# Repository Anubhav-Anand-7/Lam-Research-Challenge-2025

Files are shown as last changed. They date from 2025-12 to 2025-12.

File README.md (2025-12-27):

# Circuit Raja – Hardware Hustle: Lam Research Challenge 2025

## Overview
This repository contains the complete system design and technical implementation for the **Hardware Hustle Round : Lam Research Challenge 2025**, developed by **Team Circuit Raja (Team ID: LRC-U-0053-6)**.

The solution consists of two coordinated robots and a centralized arena automation system designed to operate reliably under real-time constraints and complete all tasks within the competition time limit.

---

## System Architecture
The system follows a **Decentralized & Deterministic Control Philosophy** to eliminate latency bottlenecks and ensure predictable behavior.

### Major Subsystems
- **Advanced Line Follower Robot (ALFR)** – Autonomous navigation and safety
- **Single Arm Robot (SARM)** – Manual operation with automated manipulation
- **Arena Automation System** – Event-driven gate control
- **Custom Peristaltic Pump** – Precision fluid dispensing

---

## Advanced Line Follower Robot (ALFR)
- 8-channel analog line sensor array with **PD control**
- **Interrupt-driven ultrasonic obstacle detection** for instant emergency stops
- High-speed, stable navigation through sharp curves and S-paths
- Line re-acquisition using last-known turn memory
- Constrained motor control for safe and consistent behavior

---

## Single Arm Robot (SARM)
- **Dual-ESP32 decentralized architecture**
  - **Base Controller:** Mecanum wheel mobility and kinematics
  - **Arm Controller:** 5-DOF robotic arm and gripper control
- Omni-directional movement for precise obstacle handling
- Predefined arm **state macros** for fast, repeatable manipulation
- **Dual-pilot operation** using two independent Bluetooth Android apps
- Modified gripper with high-friction compliant padding for reliable pickup

---

## Arena Circuitry & Automation
- Centralized MCU with **non-blocking firmware design**
- **Gate 1:** Relay-controlled peristaltic pump dispensing exactly **125 mL**
- **Gate 2:** 5-second LED activation using `millis()` (non-blocking)
- **Gate 3:** Load cell (HX711) based weight verification
- TFT display showing team identity and real-time weight data

---

## Peristaltic Pump
- Custom 3D-printed positive displacement pump
- Three-roller design for continuous, backflow-free operation
- Flow rate derived analytically and calibrated experimentally
- Software-adjustable timing to maintain ±5% volume accuracy

---

## Key Design Highlights
- Deterministic PD control over heuristic methods
- Hardware interrupts for safety-critical sensing
- Parallel execution using multi-core and multi-operator strategies
- Fully non-blocking arena automation logic

---

## Team
**Circuit Raja**  
Hardware Hustle – Lam Research Challenge 2025  
Submission Date: **November 2025**

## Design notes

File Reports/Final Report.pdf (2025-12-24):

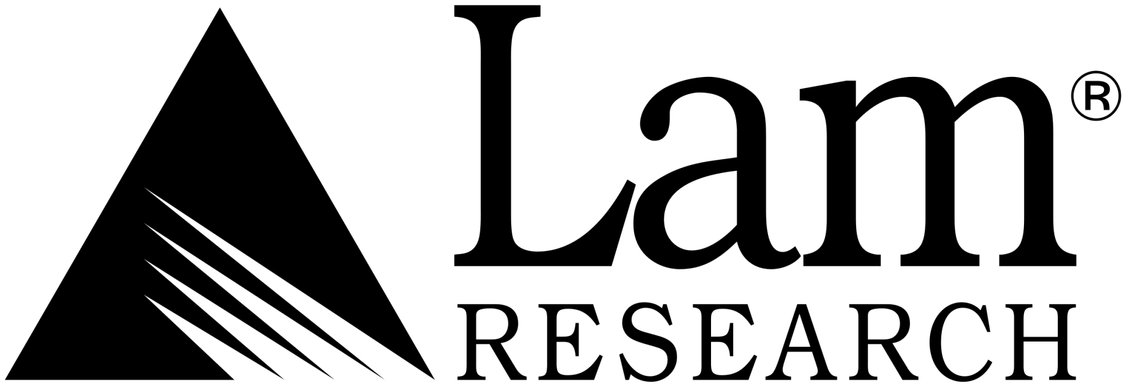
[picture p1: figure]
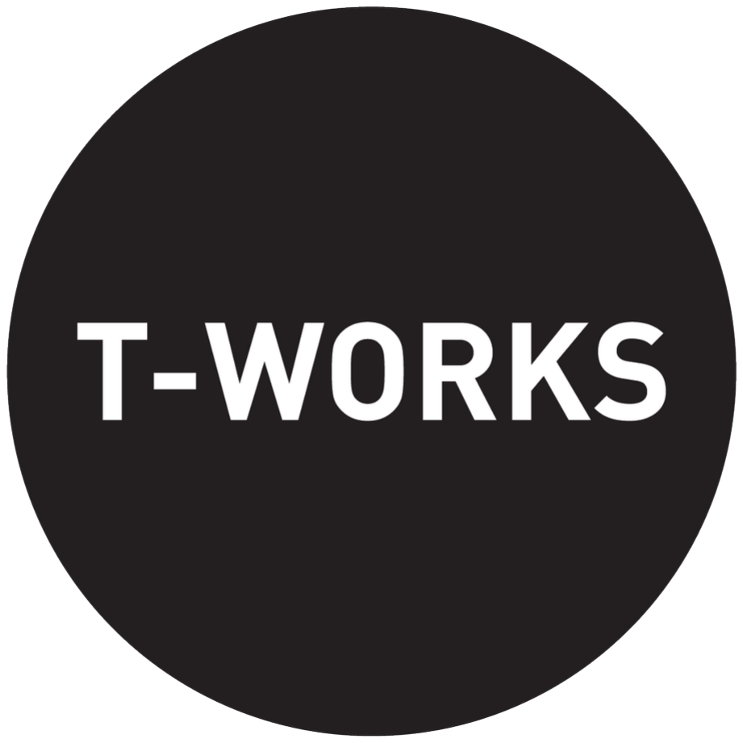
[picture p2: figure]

# Hardware Hustle: Lam Research Challenge 2025

### Design Technical Documentation

Submitted By:

# Circuit Raja

Team ID: LRC-U-0053-6

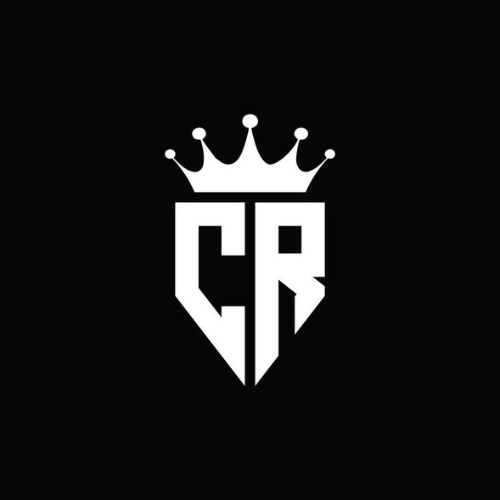
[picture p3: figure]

November 2025

Circuit Raja | Hardware Hustle: Lam Research Challenge 2025

### Contents

1 System Overview | 2
2 Advanced Line Follower Robot (ALFR) | 3
3 Single Arm Robot (SARM) Design | 5
4 Arena Circuitry & Automation Design | 7
5 Peristaltic Pump Development | 9
Confidential Design Document | Page 1

### 1 System Overview

### 1.1 Problem Statement Overview

The Hardware Hustle challenge requires two coordinated robots—a manually controlled Single Arm Robot (SARM) and an autonomous Advanced Line Follower Robot (ALFR)—to complete a sequence of tasks inside a predefined arena. ALFR must follow the line path, halt at obstacles, trigger Gate 1 for fluid dispensing, Gate 2 for LED activation, and park at Gate 3 for load-cell weight verification. SARM’s role is to remove obstacles blocking ALFR’s route. The entire system must operate accurately and finish within the 10-minute time limit.

### 1.2 Design Philosophy: Decentralized & Deterministic

Our team adopted a philosophy of “Decentralized Architecture & Deterministic Control.” Analyzing the complexity of the Hardware Hustle challenge, we determined that a single microcontroller loop would introduce unacceptable latency when handling simultaneous tasks—such as inverse kinematics, sensor interrupts, and wireless communication. Therefore, we engineered a system where critical subsystems operate on independent processing cores. This ensures that heavy computational tasks never block safety-critical functions like obstacle detection. We prioritized predictability over raw speed, using mathematical models (PID) and hardware interrupts to guarantee the robot behaves exactly the same way in every run.

### 1.3 Technical Implementation Strategies

1. SARM: Dual-Core Decentralization
To ensure zero latency during the manual operation phase, the Single Arm Robot (SARM) utilizes a split-architecture approach, as detailed in our firmware source files:
- Base Controller (Mobility): A dedicated ESP32 handles the Mecanum wheel kinematics. The code processes directional vectors (Forward, Backward, Strafe Left/Right) and maps them to the L298N drivers independently of the arm’s status.
- Arm Controller (Manipulation): A second ESP32 manages the 5-DOF servo arm. We
implemented “State Macros” such as moveArmContracted() and moveArmExpanded().
These macros allow the operator to trigger complex folding sequences with a single button press, ensuring the gripper geometry is always perfectly aligned for obstacle pickup.
2. ALFR: Interrupt-Driven Safety Layer
For the Autonomous Line Follower, we moved away from standard polling loops to achieve deterministic safety:
- Hardware Interrupts: We utilized a hardware Interrupt Service Routine (ISR) for the ultrasonic sensor (echoISR). This allows the emergencyStop flag to trigger in microseconds, instantly overriding the motor drivers the moment an object is detected, regardless of the main loop’s cycle time.
- PID Stabilization: We implemented a Proportional-Derivative control loop to handle the arena’s S-curves.
PIDvalue = (Kp × Error) + (Kd × (Error − PreviousError)) | (1)

With tuned constants (Kp = 40, Kd = 6), the robot adjusts motor differential speed dynamically based on the weighted average of the 8-channel sensor array.

3. Arena: Non-Blocking Automation
The Arena Controller serves as the central logic node. To satisfy the Gate 2 requirement without freezing the system, we utilized a millis() based non-blocking timer rather than delay(). This ensures the controller can still read the Gate 3 Load Cell sensors even while the Gate 2 LEDs are active.

### 2 Advanced Line Follower Robot (ALFR)

### 2.1 Mechanical Integration

The ALFR chassis is a custom 3D-printed assembly designed for low center-of-mass stability.

- Sensor Placement: The 8-channel analog line sensor array is mounted at the extreme anterior of the chassis. This forward offset provides a crucial “look-ahead” buffer, allowing the PID algorithm to react to the arena’s sharp radii (R140mm and R150mm) before the drive wheels reach the curve.
- Obstacle Detection: An HC-SR04 ultrasonic sensor is mounted centrally at a height of 40mm, optimized to detect the standard obstacle blocks used in Stages 1, 2, and 3.

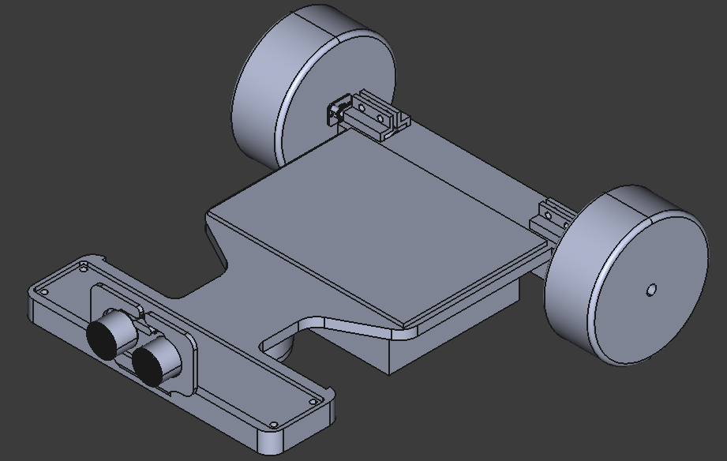
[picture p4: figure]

Figure 1: ALFR CAD

### 2.2 Control Algorithms

Unlike basic threshold-based followers, our ALFR utilizes a deterministic PD (Proportional-Derivative) control loop to ensure smooth trajectory maintenance.

### 1. PD Implementation

The core navigation logic calculates the positional error relative to the center of the sensor array. This error is processed through the following control equation:

Correction = (Kp · Error) + (Kd

- (Error − Errorprev)) | (2)

Based on our testing, we tuned the gain constants to:

- Proportional Gain (Kp = 40.0): Provides immediate reaction to track deviation.
- Derivative Gain (Kd = 6.0): Dampens oscillations, preventing the robot from “fishtailing” on straight sections.

This mathematical approach allows the ALFR to vary the motor differential speed dynamically (‘dynBase‘), maintaining a high base speed while slowing down only as much as necessary for turns.

### 2. Interrupt-Driven Obstacle Avoidance

To strictly adhere to the rule that the ALFR must “Wait if Obstacle Present” (Rulebook Page 4), we implemented a hardware-interrupt safety layer.
Instead of polling the sensor in the main loop (which can be delayed by PID calculations), we attached an Interrupt Service Routine (ISR) to the Ultrasonic Echo pin:

void echoISR() {
// Calculates distance immediately upon signal return
if (distance < 20) emergencyStop = true;
}

This architecture ensures that if an obstacle is placed within 20cm, the robot halts in microseconds, independent of the main processor load.

### 2.3 Code Uniqueness

- Memory Buffer: The system utilizes a lastTurn variable. If the robot completely loses the line (e.g., at a sharp acute angle), it recalls the direction of the last known error and performs a rotational search in that direction until the line is re-acquired.
- Hardware-Level Pin State Check: Rising/falling edges of the echo signal are detected by checking

if (PIND & (1 << PIND3))
This is faster and more precise than using digitalRead(), giving microsecond accuracy to
the distance measurement.
- Constrained Motor Control for Safe Behavior: Motor outputs are bounded using constrain() to ensure safe acceleration and consistent turning behavior. This prevents electrical and mechanical stress on the motors during sharp PID corrections.

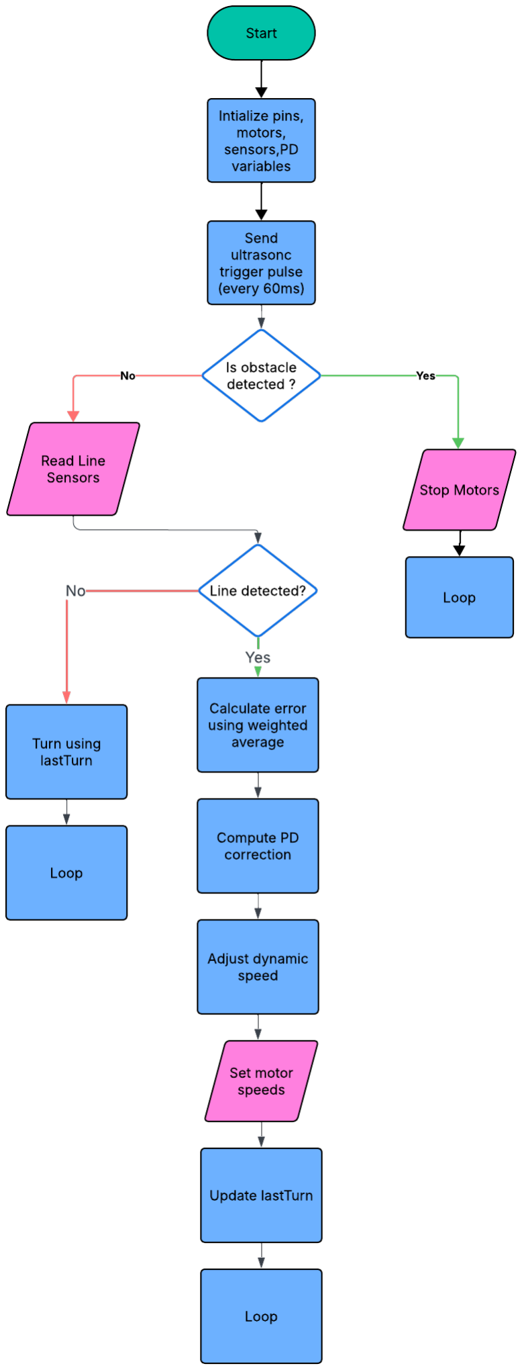
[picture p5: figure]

Figure 2: ALFR Algorithm flowchart

### 3 Single Arm Robot (SARM) Design

### 3.1 Control Architecture: Dual-Core Decentralization

To mitigate latency and ensure real-time responsiveness during the manual operation phase, we developed a Decentralized Control System. Unlike traditional single-board designs, our SARM separates mobility and manipulation into independent processing nodes:

- Node A (Mobility Controller): An ESP32 running SARM base code.ino is dedicated exclusively to the Mecanum wheel inverse kinematics. It parses directional vectors (Forward, Strafe, Rotate) via Bluetooth without servo signal interference.
- Node B (Arm Controller): A secondary ESP32 running Final SARM arm code.ino manages the 5-DOF robotic arm. This separation ensures that the PWM signals for the servos remain stable even when the motors are drawing high current during rapid acceleration.

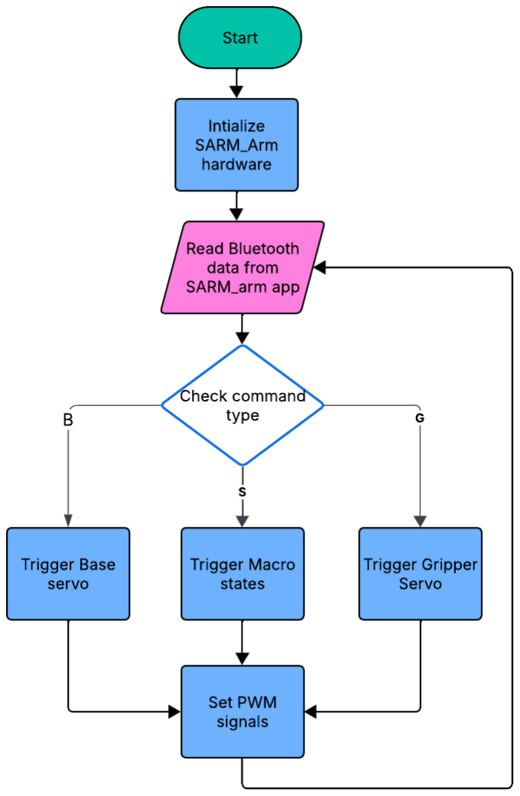
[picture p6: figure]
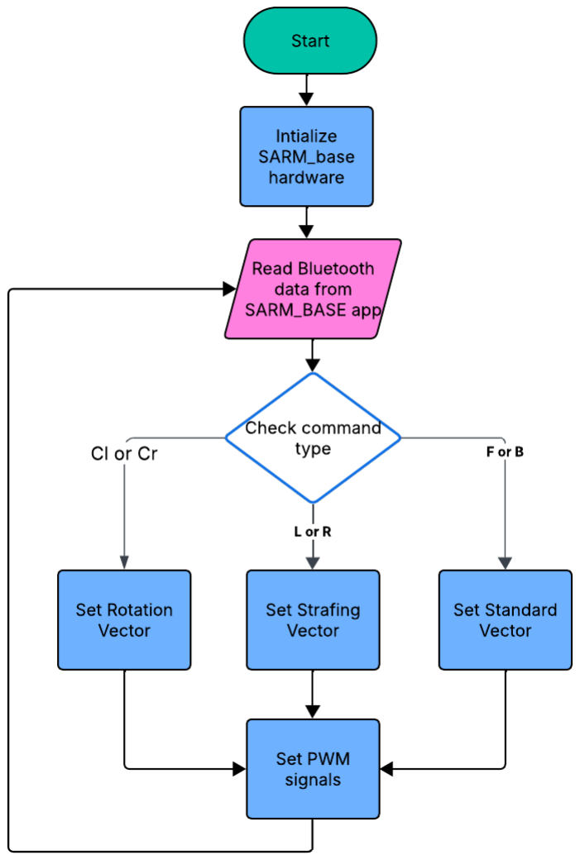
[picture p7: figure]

Figure 3: Node A Algorithm flowchart | Figure 4: Node B Algorithm flowchart

### 3.2 Omni-Directional Mobility

The base utilizes four independently driven Mecanum wheels. The drive logic leverages vector cancellation to achieve holonomic movement. As implemented in our firmware function void
left():

// Vector Math for Left Strafe
Motor1 (Front-Left): Backward Motor2 (Front-Right): Forward

Motor3 (Rear-Right): | Forward
Motor4 (Rear-Left): | Backward

This configuration allows the operator to align with obstacles laterally without needing to perform complex multi-point turns, significantly reducing cycle time.

### 3.3 Automated Manipulation Logic

To minimize operator fatigue and error, we moved away from raw manual control for every joint. Instead, we implemented State Macros pre-calculated geometric configurations hardcoded into the firmware.

- Contracted State (Safety): Defined in code as contracted shoulder = 140, this macro folds the arm entirely within the chassis footprint. This allows the robot to travel at maximum speed without the arm changing the center of gravity or colliding with arena walls.
- Expanded/Grip State: Defined as expanded elbow = 30, this macro automatically positions the end-effector at the exact height of the obstacle blocks (Z ≈ 40mm), removing the need for the operator to manually estimate depth.

### 3.4 Dual-Pilot Operational Strategy

Innovation: Two Apps, Two Pilots, Zero Lag
To overcome the inherent latency limitations of standard Bluetooth stacks and reduce the cognitive load on a single operator, we engineered a Split-Control HMI (Human-Machine Interface).
Instead of a single app, we developed two distinct custom Android applications:
1. Pilot App (Navigation): Pairs exclusively with the Base ESP32 (“SARM BASE”). This allows the primary pilot to focus solely on high-speed maneuvering and obstacle approach vectors.
2. Co-Pilot App (Manipulation): Pairs exclusively with the Arm ESP32 (“ESP32 ARM”). This allows the secondary pilot to trigger the gripper macros (Open/Close, Fold/Extend) independently.

Strategic Advantage: This ‘Rally Car’ style coordination (Driver + Navigator) allows the arm to begin unfolding while the base is still moving toward the target. This parallel execution effectively doubles our operational bandwidth and significantly reduces the total cycle time per obstacle compared to a single-pilot workflow.

### 3.5 Gripper Design & Modification

The standard gripper design provided in the reference kit was analyzed and found to lack sufficient friction for the arena obstacles. To address this, we engineered the following modifications:

1. Adaptive Contact Geometry: Unlike a rigid geometric modification, we retained the standard gripper structure but integrated a compliant interface. The compressible nature of the foam pads allows the jaw profile to dynamically deform and mold itself to the obstacle’s shape, effectively increasing the contact surface area upon closure.

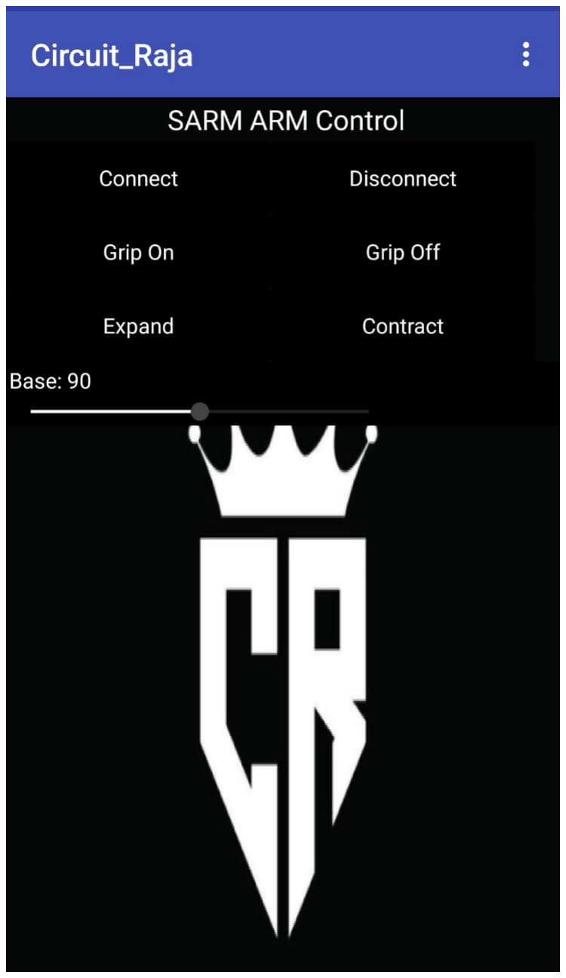
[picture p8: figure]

Figure 5: SARM
Arm GUI

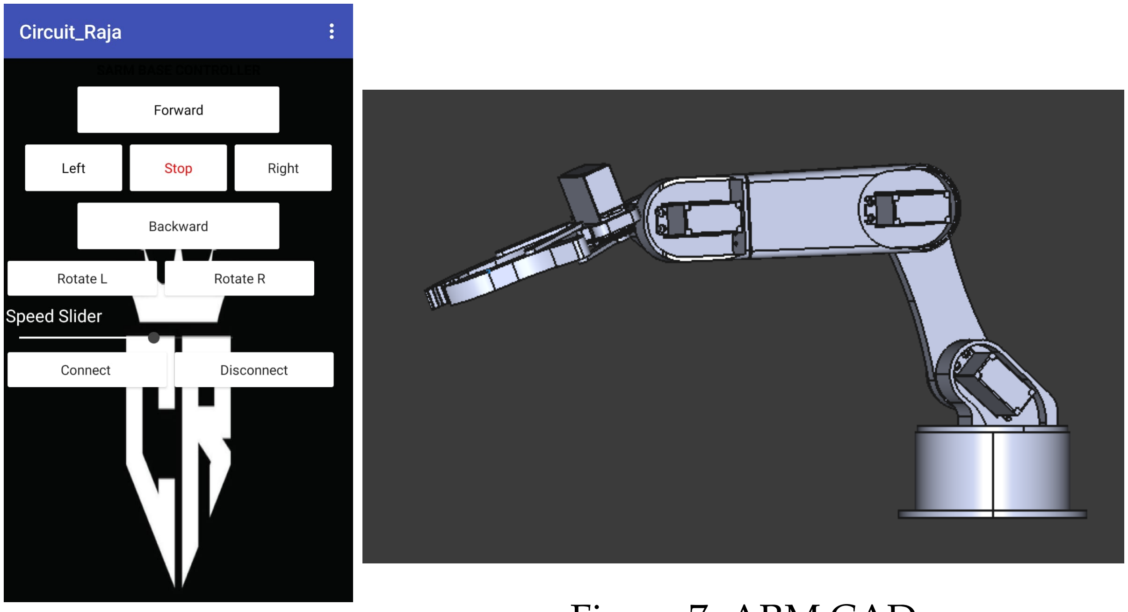
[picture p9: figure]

Figure 6: SARM
Base GUI

Figure 7: ARM CAD

2. Surface Material Enhancement: We applied high-density adhesive foam padding to the inner jaw faces. This modification significantly increases the coefficient of friction compared to bare PLA and provides mechanical damping, ensuring the obstacle does not slip or vibrate loose during high-speed acceleration.
3. Kinematic Redesign (5-Bar to 4-Bar Conversion): The original gripper design utilized a 5-bar linkage mechanism, which is under-actuated when driven by a single motor. To resolve this instability, we rigidly fixed two of the intermediate links at the pivot joint.

### 4 Arena Circuitry & Automation Design

### 4.1 Centralized Arena Control Architecture

To ensure synchronized game states across all three stages, we implemented a Centralized Event-Driven Architecture. A single Microcontroller Unit (MCU) monitors the state of all three gates simultaneously.
Unlike basic sequential systems, our firmware utilizes Non-Blocking I/O logic. This allows the system to manage the Gate 2 LED timers while simultaneously polling the Gate 3 Load Cell data, preventing any blind spots in the sensing loop.

### 4.2 Gate 1: Precision Fluid Delivery System

Objective: Dispense exactly 125ml of fluid upon ALFR detection.

- Hardware Integration: We utilized a 5V Relay Module (controlled via Pin 14) to switch the high-current DC Peristaltic Pump. The trigger is a digital IR sensor (Pin 16) configured as INPUT PULLUP (Active LOW).
- Flow Control Logic: Instead of relying on variable voltage, we operate the pump at a fixed 12V to ensure a constant flow rate (Q). The dispense volume is controlled purely by time (t):

tdispense =

Vtarget

Qpump

(3)

The code waits for the sensorState == LOW signal to close the relay circuit.

### 4.3 Gate 2: Timer-Based LED Activation

Objective: Illuminate the Lam LED array for 5 seconds without blocking system processes. Innovation - Non-Blocking Timer: Standard delay(5000) functions would freeze the processor, preventing it from detecting the robot at Gate 3 if it moved quickly. To solve this, we implemented a millis() based timer in the code:

if (sensorState2 == LOW) {
relay2Active = true; | // Set Flag
relay2TimerStart = millis(); // Start Stopwatch
}
// Check time difference in every loop cycle
if (relay2Active && (millis() - relay2TimerStart >= 5000)) {
turnOffLEDs(); | // Auto-Reset
}

This ensures the visual effects (Gate 2) do not interfere with the critical data collection (Gate 3).

### 4.4 Gate 3: Validation Node (Load Cell & LCD)

Objective: Verify fluid weight and display Team Identity.

1. Weight Sensing (HX711): We interfaced a 5kg Load Cell via an HX711 24-bit ADC (Pins 32/33). To ensure accuracy despite vibration, the code takes a 10-sample moving average (scale.get units(10)) before validating the success condition.
2. Visual Feedback (ST7735): Upon successful weight verification, the system drives an ST7735 TFT Display via SPI. As a unique team identifier, the display renders:
- Team Handle: ”Circuit RAJA”
- Custom Bitmap: smile bmp (Visual success indicator)
- Real-time Weight Value

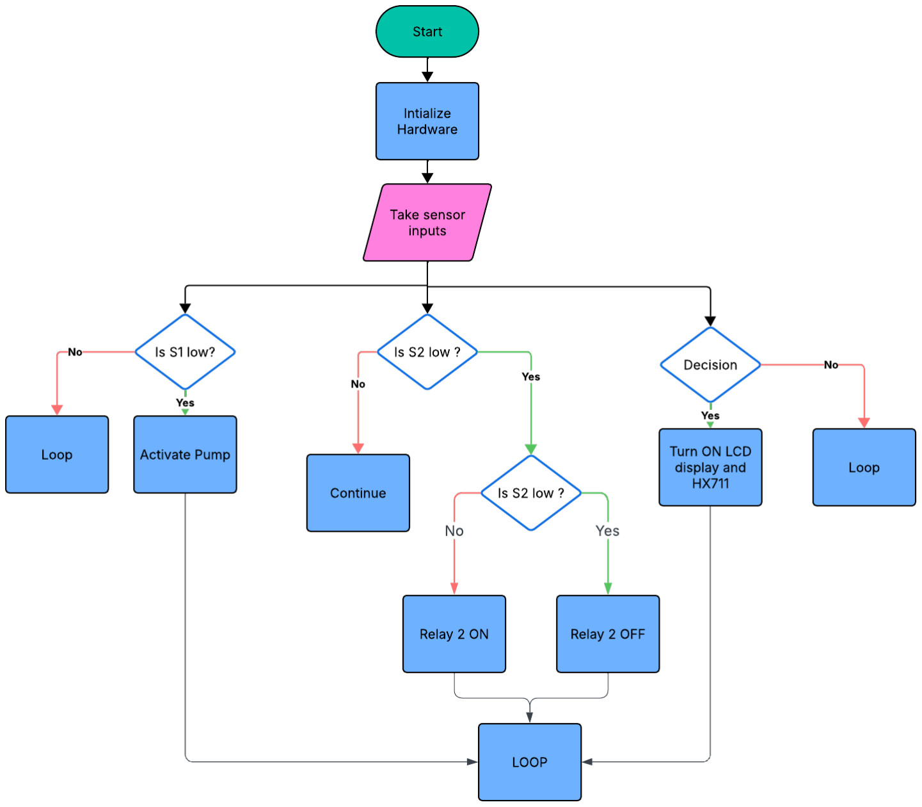
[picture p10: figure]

Figure 8: Arena Algorithm flowchart

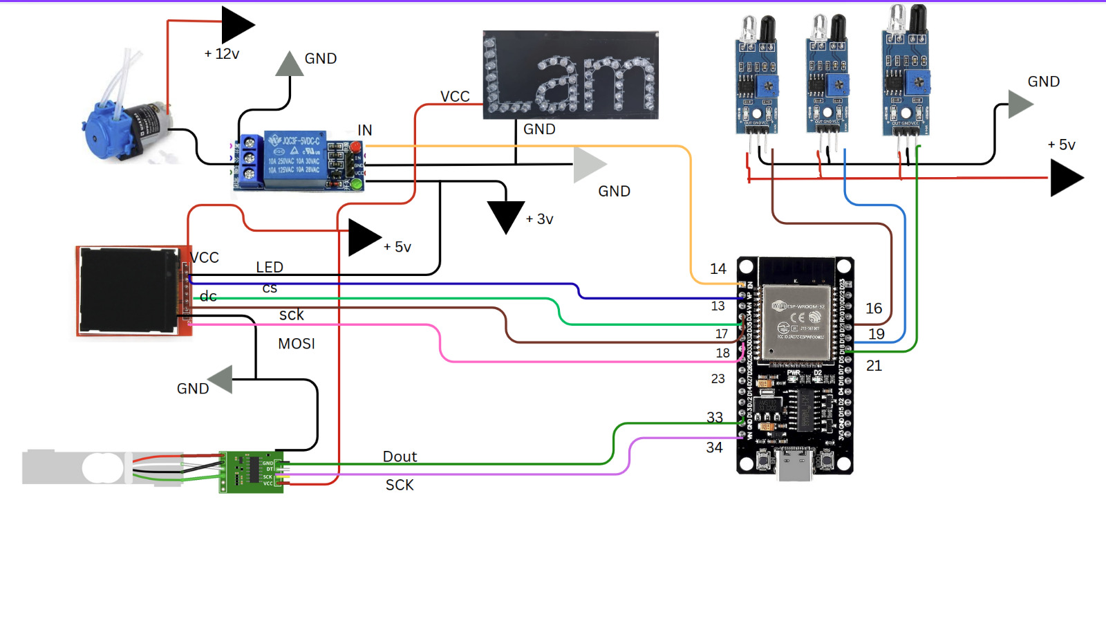
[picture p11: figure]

Figure 9: Arena Circuit Schematic

### 5 Peristaltic Pump Development

### 5.1 Mechanical Design Principle

To achieve the specific fluid delivery requirement of 125 mL at Gate 1, we engineered a custom positive displacement pump. The mechanism relies on a rotating three-roller configuration that progressively compresses a flexible silicone tube against a circular stator.

- Stator Geometry: Designed with a track radius (R) of 25 mm to support the tubing without over-compression.
- Rotor Configuration: A three-roller design was selected to ensure continuous flow and prevent backflow (siphoning) when the motor stops[cite: 273].
- Coupling: A custom-designed 3D-printed mount aligns the 600 RPM DC motor shaft directly with the rotor assembly[cite: 274, 288].

### 5.2 Flow Rate Mathematics

To strictly control the dispensed volume, we derived the theoretical flow rate based on the tubing geometry (2 mm Internal Diameter).

1. Volume per Revolution (Vrev): Using the tube cross-sectional area (A) and the path circumference (C):
Vrev = A × C ≈ 0.492mL/rev | (4)
Derived from A = 3.14 × 10⁻⁶m² and C = 0.157m[cite: 280, 283, 286].
2. Time Calculation (t): With a motor speed of 600 RPM (10rev/s) and an estimated mechanical efficiency of 90%, the actual flow rate is calculated as:
Qactual ≈ 4.43mL/s | (5)

Therefore, the required activation time to dispense 125 mL is:

t =

125mL
4.43mL/s
≈ 28seconds | (6)

This duration falls well within the competition limits.

### 5.3 Manufacturing & Calibration

The pump components (Housing and Rotor) were manufactured using FDM 3D printing with PLA/PETG filaments for structural rigidity.
Calibration Strategy: Although the theoretical calculation yields ∼ 28 seconds, we implemented a software calibration routine in the Arena Controller:
1. Run pump for fixed interval (10s).
2. Measure dispensed mass.
3. Adjust the relay1 active duration in the code based on the experimental flow rate to ensure ±5% accuracy.

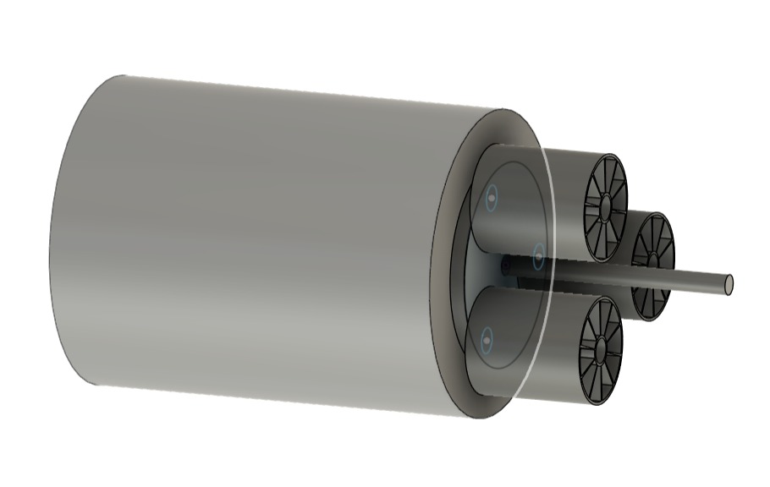
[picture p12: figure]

Figure 10: Side view of the pump

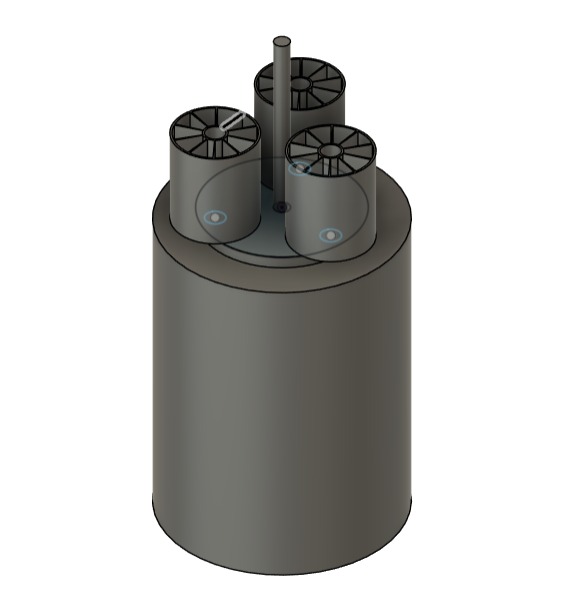
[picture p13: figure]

Figure 11: Isometric view of the pump

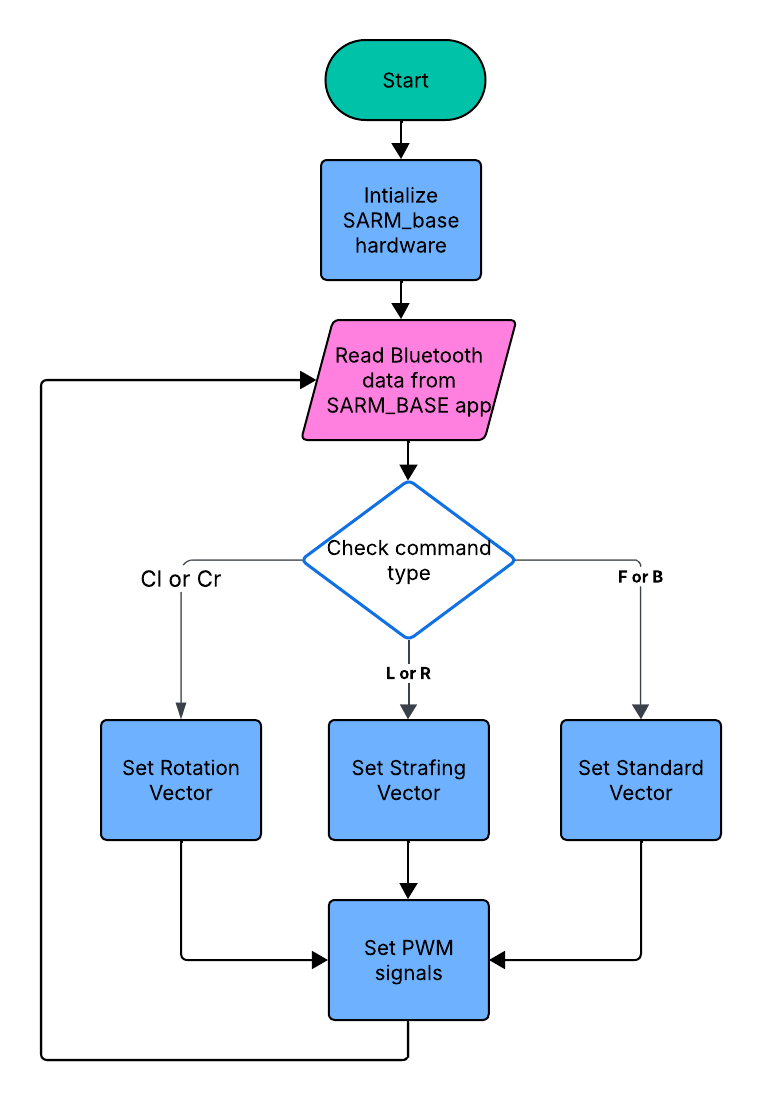
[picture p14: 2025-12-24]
Firmware & Flowchart/SARM/SARM_Base_flowchart.png

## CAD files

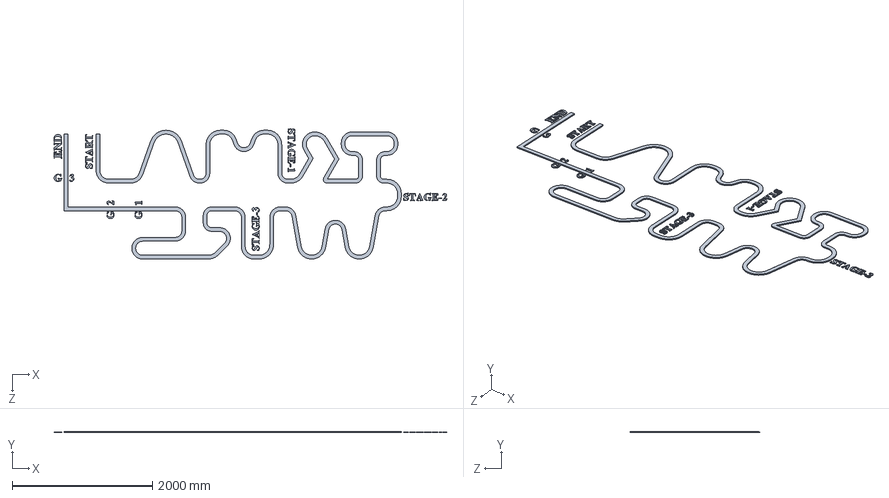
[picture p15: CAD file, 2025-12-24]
3D Files/Arena/FINAL_ARENA.SLDPRT
5611.0 x 15.0 x 1858.3 mm

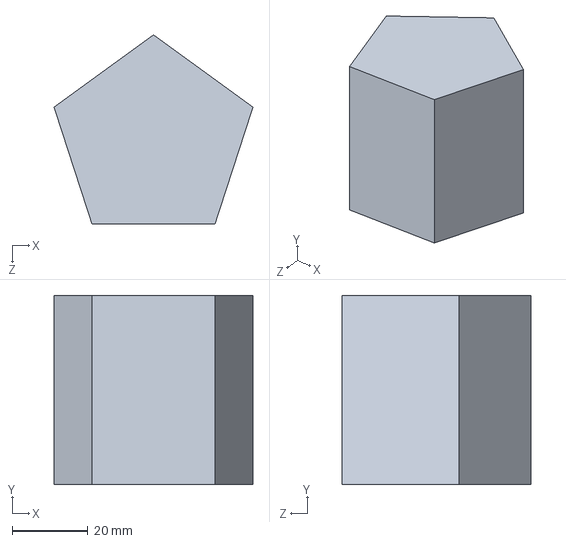
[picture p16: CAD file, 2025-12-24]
3D Files/Obstale/Obstacle.SLDPRT
52.6 x 50.0 x 50.0 mm

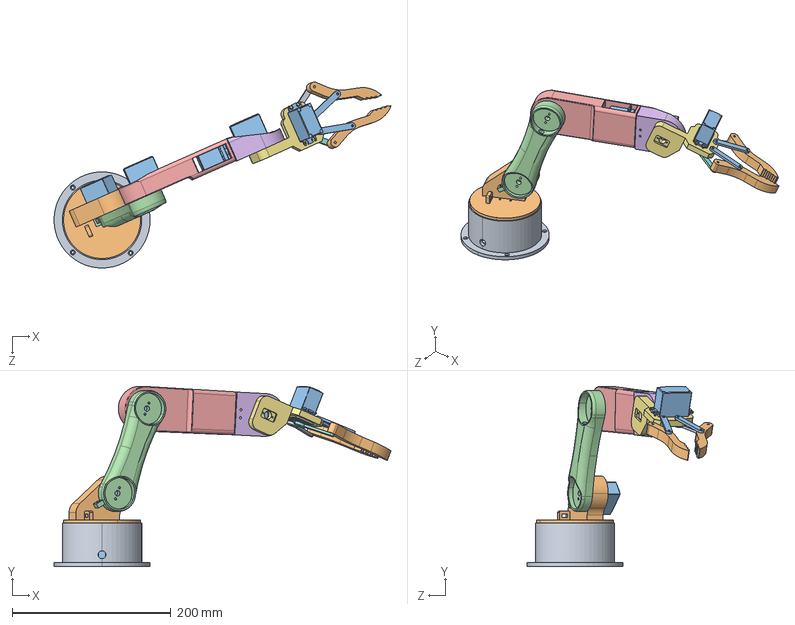
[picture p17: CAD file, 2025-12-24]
3D Files/SARM/SARM.STEP
424.3 x 227.0 x 234.2 mm
base
basecap
Servo x 6
link1
link2
link3
link4
gear1
gear2
Gripper x 2
link5 x 2

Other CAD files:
Firmware & Flowchart/Peristaltic_Pump/Peristaltic_Pump.f3d

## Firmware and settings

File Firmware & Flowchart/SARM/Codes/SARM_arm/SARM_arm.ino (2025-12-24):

#include <BluetoothSerial.h>
#include <ESP32Servo.h>

// ---------------------- BLUETOOTH -------------------------
BluetoothSerial SerialBT;

// ---------------------- SERVO OBJECTS ----------------------
Servo servoBase;
Servo servoShoulder;
Servo servoElbow;
Servo servoWrist;
Servo servoGripper;

// ---------------------- SERVO PINS -------------------------
#define PIN_BASE       26
#define PIN_SHOULDER   27
#define PIN_ELBOW      32
#define PIN_WRIST      23
#define PIN_GRIPPER    19

// ---------------------- TIMING & TUNING -------------------
int stepDelayDefault = 8;   // ms delay between interpolation steps (increase to slow down motion)
int minSteps = 20;          // minimum number of interpolation steps (prevents very few large jumps)
int safety_margin = 2;      // degrees of extra safety margin to avoid chassis contact

// ---------------------- ARM ANGLES -------------------------
// CONTRACTED STATE
int contracted_shoulder = 140;
int contracted_elbow    = 110;
int up_wrist            = 130;
int contracted_gripper  = 10;

// EXPANDED STATE
int contracted_base     = 90;
int expanded_shoulder   = 10;
int expanded_elbow      = 45;
int down_wrist          = 100;
int expanded_gripper    = 90;

// ---------------------- SETUP ------------------------------
void setup() {
  Serial.begin(115200);
  SerialBT.begin("ESP32_ARM");

  ESP32PWM::allocateTimer(0);
  ESP32PWM::allocateTimer(1);
  ESP32PWM::allocateTimer(2);
  ESP32PWM::allocateTimer(3);

  servoBase.attach(PIN_BASE, 500, 2400);
  servoShoulder.attach(PIN_SHOULDER, 500, 2400);
  servoElbow.attach(PIN_ELBOW, 500, 2400);
  servoWrist.attach(PIN_WRIST, 500, 2400);
  servoGripper.attach(PIN_GRIPPER, 500, 2400);

  // Start in CONTRACTED STATE
  servoBase.write(contracted_base);
  servoShoulder.write(contracted_shoulder);
  servoElbow.write(contracted_elbow);
  servoWrist.write(up_wrist);
  servoGripper.write(contracted_gripper);

  Serial.println("Manipulator Ready via USB & Bluetooth!");
  SerialBT.println("Manipulator Ready via Bluetooth!");

  Serial.println("Commands:\nB x\nG 0-90\nS 0 or 1");
  SerialBT.println("Commands:\nB x\nG 0-90\nS 0 or 1");
}

// -----------------------------------------------------------
//  INTERPOLATED SYNCHRONIZED MOVEMENT (both move in proportion)
// -----------------------------------------------------------
void smoothMoveSyncInterpolated(Servo &s1, int start1, int target1,
                                Servo &s2, int start2, int target2,
                                int stepDelay = -1) {
  if (stepDelay < 0) stepDelay = stepDelayDefault;

  int delta1 = target1 - start1;
  int delta2 = target2 - start2;

  int steps = max(abs(delta1), abs(delta2));
  steps = max(steps, minSteps); // ensure we have reasonable number of steps

  for (int i = 1; i <= steps; ++i) {
    float frac = (float)i / (float)steps; // progress 0..1

    // linear interpolation
    int pos1 = start1 + round(delta1 * frac);
    int pos2 = start2 + round(delta2 * frac);

    // Safety: ensure elbow never goes beyond the interpolated safe value
    // (This prevents elbow outrunning shoulder in contraction/expansion)
    // If s1 == shoulder and s2 == elbow this helps; if different usage, fine.
    // We add a small safety margin to be conservative.
    // NOTE: This logic assumes s1 is shoulder and s2 is elbow for contractions/expansions call.
    // If you call this for other pairs, it does no harm (simple interp).
    // We only enforce the constraint in situations where start/target imply contracted <-> expanded.
    // Compute expected elbow based on shoulder fraction of progress:
    int expected_elbow = start2 + round(delta2 * frac);

    // pos2 should not be "ahead" of expected_elbow by more than margin
    if ((delta2 > 0 && pos2 > expected_elbow + safety_margin) ||
        (delta2 < 0 && pos2 < expected_elbow - safety_margin)) {
      pos2 = expected_elbow + (delta2 > 0 ? safety_margin : -safety_margin);
    }

    // apply positions
    s1.write(constrain(pos1, 0, 180));
    s2.write(constrain(pos2, 0, 180));

    delay(stepDelay);
  }

  // ensure final exact targets
  s1.write(constrain(target1, 0, 180));
  s2.write(constrain(target2, 0, 180));
}

// -----------------------------------------------------------
//  INDIVIDUAL SMOOTH MOVEMENT (For Base and Gripper)
// -----------------------------------------------------------
void smoothMove(Servo &servo, int target, int stepDelay = -1) {
  if (stepDelay < 0) stepDelay = stepDelayDefault;

  int current = servo.read();
  int delta = target - current;
  int steps = max(abs(delta), minSteps);

  for (int i = 1; i <= steps; ++i) {
    float frac = (float)i / (float)steps;
    int pos = current + round(delta * frac);
    servo.write(constrain(pos, 0, 180));
    delay(stepDelayDefault);
  }
  servo.write(constrain(target, 0, 180));
}

// -----------------------------------------------------------
//  ARM STATE MOVEMENTS (use interpolated sync)
// -----------------------------------------------------------
void moveArmContracted() {
  int startShoulder = servoShoulder.read();
  int startElbow    = servoElbow.read();

  // Use interpolated sync: both move proportionally from current -> contracted
  smoothMoveSyncInterpolated(servoShoulder, startShoulder, contracted_shoulder,
                             servoElbow,    startElbow,    contracted_elbow,
                             stepDelayDefault);

  Serial.println("Moved to CONTRACTED state");
  SerialBT.println("Moved to CONTRACTED state");
}

void moveArmExpanded() {
  int startShoulder = servoShoulder.read();
  int startElbow    = servoElbow.read();

  smoothMoveSyncInterpolated(servoShoulder, startShoulder, expanded_shoulder,
                             servoElbow,    startElbow,    expanded_elbow,
                             stepDelayDefault);

  Serial.println("Moved to EXPANDED state");
  SerialBT.println("Moved to EXPANDED state");
}

// -----------------------------------------------------------
//  COMMAND PARSER
// -----------------------------------------------------------
void processCommand(String cmd) {
  cmd.trim();

  // BASE CONTROL: B <angle>
  if (cmd.startsWith("B")) {
    int angle = cmd.substring(2).toInt();
    angle = constrain(angle, 0, 180);

    servoBase.write(angle);

    Serial.printf("Base → %d°\n", angle);
    SerialBT.printf("Base → %d°\n", angle);
  }

  // Wrist: W <angle>
  else if (cmd.startsWith("W")) {
    int angle = cmd.substring(2).toInt();
    angle = constrain(angle, down_wrist, up_wrist);

    servoWrist.write(angle);

    Serial.printf("Wrist → %d°\n", angle);
    SerialBT.printf("Wrist → %d°\n", angle);
  }

  // Gripper: G <angle>
  else if (cmd.startsWith("G")) {
    int angle = cmd.substring(2).toInt();
    angle = constrain(angle, 0, 80);

    servoGripper.write(angle);

    Serial.printf("Gripper → %d°\n", angle);
    SerialBT.printf("Gripper → %d°\n", angle);
  }

  // ARM STATE: S 0 or S 1
  else if (cmd.startsWith("S")) {
    int st = cmd.substring(2).toInt();

    if (st == 0) moveArmContracted();
    else if (st == 1) moveArmExpanded();
  }

  else {
    Serial.println("Invalid Command!");
    SerialBT.println("Invalid Command!");
  }
}

// -----------------------------------------------------------
//  MAIN LOOP
// -----------------------------------------------------------
void loop() {

  // USB input
  if (Serial.available()) {
    String input = Serial.readStringUntil('\n');
    processCommand(input);
  }

  // Bluetooth input
  if (SerialBT.available()) {
    String input = SerialBT.readStringUntil('\n');
    processCommand(input);
  }
}

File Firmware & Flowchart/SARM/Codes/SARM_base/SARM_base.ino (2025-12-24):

#include "BluetoothSerial.h"

BluetoothSerial SerialBT;

// ----------------------------
// MOTOR PIN ASSIGNMENTS
// ----------------------------

// L298N #1
int M1_PWM = 19;
int M1_IN1 = 21;
int M1_IN2 = 3;

int M2_PWM = 23;
int M2_IN1 = 1;
int M2_IN2 = 22;

// L298N #2
int M3_PWM = 0;
int M3_IN1 = 4;
int M3_IN2 = 16;

int M4_PWM = 18;
int M4_IN1 = 17;
int M4_IN2 = 5;

// Speed
int speedVal = 128;   // 0–255 for ESP32 LEDC

// ----------------------------
// helper function
// ----------------------------
void setMotor(int in1, int in2, int pwmPin, int direction, int spd)
{
  digitalWrite(in1, direction == 1 ? HIGH : LOW);
  digitalWrite(in2, direction == 1 ? LOW : HIGH);
  ledcWrite(pwmPin, spd);
}

// ----------------------------
// MOVEMENT FUNCTIONS
// ----------------------------

void forward()
{
  setMotor(M1_IN1, M1_IN2, M1_PWM, 1, speedVal);
  setMotor(M2_IN1, M2_IN2, M2_PWM, 1, speedVal);
  setMotor(M3_IN1, M3_IN2, M3_PWM, 1, speedVal);
  setMotor(M4_IN1, M4_IN2, M4_PWM, 1, speedVal);
   Serial.println("Forward");
}

void backward()
{
  setMotor(M1_IN1, M1_IN2, M1_PWM, 0, speedVal);
  setMotor(M2_IN1, M2_IN2, M2_PWM, 0, speedVal);
  setMotor(M3_IN1, M3_IN2, M3_PWM, 0, speedVal);
  setMotor(M4_IN1, M4_IN2, M4_PWM, 0, speedVal);
     Serial.println("Backward");

}

void left()   // strafe left
{
  setMotor(M1_IN1, M1_IN2, M1_PWM, 0, speedVal);
  setMotor(M2_IN1, M2_IN2, M2_PWM, 1, speedVal);
  setMotor(M3_IN1, M3_IN2, M3_PWM, 1, speedVal);
  setMotor(M4_IN1, M4_IN2, M4_PWM, 0, speedVal);
     Serial.println("Left");

}

void right()  // strafe right
{
  setMotor(M1_IN1, M1_IN2, M1_PWM, 1, speedVal);
  setMotor(M2_IN1, M2_IN2, M2_PWM, 0, speedVal);
  setMotor(M3_IN1, M3_IN2, M3_PWM, 0, speedVal);
  setMotor(M4_IN1, M4_IN2, M4_PWM, 1, speedVal);
     Serial.println("Right");

}

void rotateLeft()
{
  setMotor(M1_IN1, M1_IN2, M1_PWM, 0, speedVal);
  setMotor(M2_IN1, M2_IN2, M2_PWM, 1, speedVal);
  setMotor(M3_IN1, M3_IN2, M3_PWM, 0, speedVal);
  setMotor(M4_IN1, M4_IN2, M4_PWM, 1, speedVal);
     Serial.println("Rotateleft");

}

void rotateRight()
{
  setMotor(M1_IN1, M1_IN2, M1_PWM, 1, speedVal);
  setMotor(M2_IN1, M2_IN2, M2_PWM, 0, speedVal);
  setMotor(M3_IN1, M3_IN2, M3_PWM, 1, speedVal);
  setMotor(M4_IN1, M4_IN2, M4_PWM, 0, speedVal);
     Serial.println("RotateRight");

}

void stopAll()
{
  ledcWrite(M1_PWM, 0);
  ledcWrite(M2_PWM, 0);
  ledcWrite(M3_PWM, 0);
  ledcWrite(M4_PWM, 0);
     Serial.println("Stop");

}

// ----------------------------
// SETUP
// ----------------------------
void setup()
{
  Serial.begin(115200);
  SerialBT.begin("SARM_BASE");

  ESP32PWM::allocateTimer(0);
  ESP32PWM::allocateTimer(1);
  ESP32PWM::allocateTimer(2);
  ESP32PWM::allocateTimer(3);

  // Direction pins
  pinMode(M1_IN1, OUTPUT); pinMode(M1_IN2, OUTPUT);
  pinMode(M2_IN1, OUTPUT); pinMode(M2_IN2, OUTPUT);
  pinMode(M3_IN1, OUTPUT); pinMode(M3_IN2, OUTPUT);
  pinMode(M4_IN1, OUTPUT); pinMode(M4_IN2, OUTPUT);
 
  ledcAttach(M1_PWM, 1000, 8);
  ledcAttach(M2_PWM, 1000, 8);
  ledcAttach(M3_PWM, 1000, 8);
  ledcAttach(M4_PWM, 1000, 8);

  stopAll();
}

// ----------------------------
// MAIN LOOP
// ----------------------------
void loop() {
  
  if (SerialBT.available())
  {
    String cmd = SerialBT.readStringUntil('\n');
    cmd.trim();

    if (cmd == "F") forward();
    else if (cmd == "B") backward();
    else if (cmd == "L") left();
    else if (cmd == "R") right();
    else if (cmd == "S") stopAll();
    else if (cmd == "CL") rotateLeft();
    else if (cmd == "CR") rotateRight();
  }
  delay(10);
}
